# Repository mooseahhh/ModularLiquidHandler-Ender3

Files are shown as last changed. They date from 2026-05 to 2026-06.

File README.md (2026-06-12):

# Modular, Remotely Accessible, Open Source Liquid Handler — Ender 3 Pro
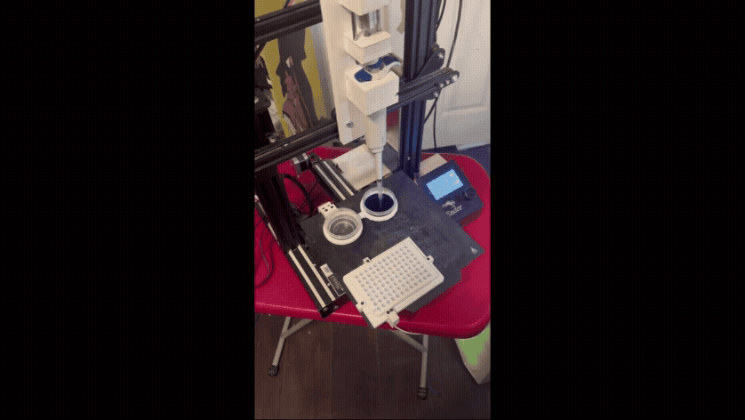
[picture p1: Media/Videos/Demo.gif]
Liquid handler demo


### Commercial liquid handlers can cost thousands of dollars and often offer little modularity. This project showcases a fully functional, remote-access capable liquid handler built by modifying a used Ender 3 Pro 3D printer for **under $150**.

## Features
- **Low Cost** —
  - Base build under $150 using a used/refurbished Ender 3 Pro; accessible without institutional funding
- **Modular Hardware** —
  - Built on a widely-supported 3D printer platform running open-source Marlin firmware; components are replaceable and the design is forkable
- **Precise, Calibrated Dispensing** —
  - semi-automated gravimetric calibration workflow CV% tracked as a primary acceptance metric  following ISO 8655 gravimetric principles
  - Well alignment, pipette well and reservoir immersion tests
- **Network Connectivity** —
  - Full remote operation via network access through OctoPrint + OctoEverywhere plugin: file uploads, G-code terminal, protocol monitoring, and calibration runs without physical access
- **Flexible Scripting** —
  - Gcode generating scripts can be utilized to make simple, customizable, lab protocols in workflows
- **Demonstrated Application** —
  - 24-column, 4-step 1:2 serial dilution protocol across a full 96-well plate in a 2-hour automated run
---
## Current Validation Results
| Metric | Value |
|---|---|
| Target Volume | 125.0 µL |
| Mean Volume | 126.85 µL |
| Mean Error | +1.85 µL (+1.48%) |
| Standard Deviation | 4.10 µL |
| CV | 3.23% |
| Trial Count | 10 |
---
## Table of Contents

- [Current Validation Results](#current-validation-results)
- [Build Resources](#build-resources)
  - [BOM(Bill of Materials)](#bom-bill-of-materials)
  - [CAD](#cad)
- [Software & Plugins](#software--plugins)
- [Repository Structure](#repository-structure)
- [Calibration](#calibration)
- [Serial Dilution Protocol](#serial-dilution-protocol)
- [Checklist / Roadmap](#checklist--roadmap)
- [License](#license)

---

## Build Resources

### Bill of Materials (BOM)

**Base build cost: ~$130**

|Main Base Items| Category  | Notes |
|---|---|---|
|**Creality Ender 3 Pro (used/refurbished)** | Motion platform | XYZ gantry + E-axis repurposed for plunger actuation |
| **Four E's Scientific P1000 single-channel manual pipette** | Pipette | Set to 125µL; drives through plunger stops via actuator |
|**Custom 3D-printed clamps, well plate holder, reservoir holders** |Deck hardware| STL files included in [`/CAD/STL_files`](/CAD/STL_files/) |

Full BOM with sourcing notes: [`/References/materials/BOM.csv`](/References/materials/BOM.csv)

---

### CAD

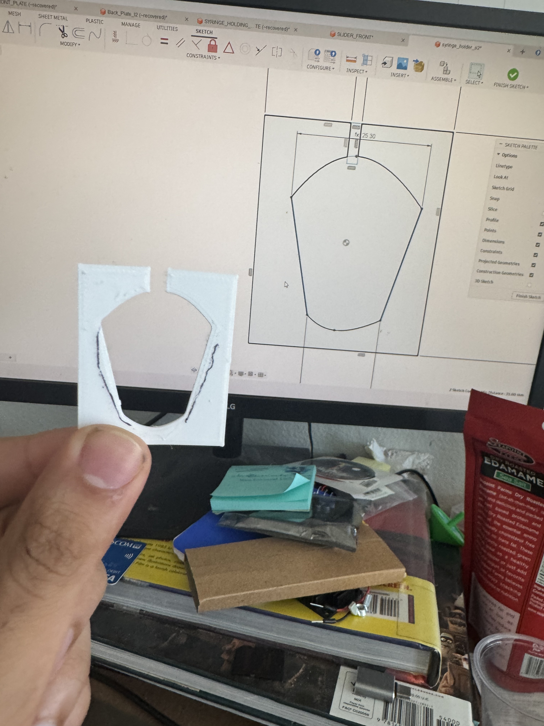
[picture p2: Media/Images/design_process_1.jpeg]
designing pipette holder


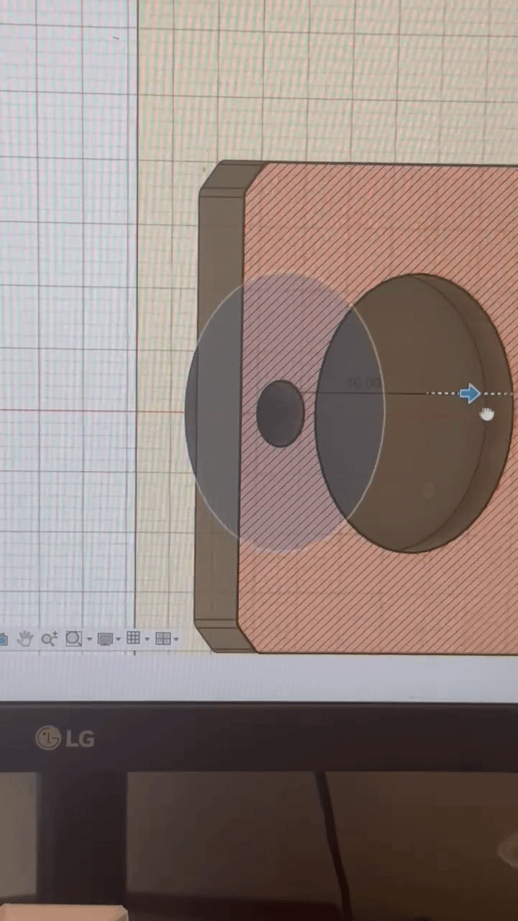
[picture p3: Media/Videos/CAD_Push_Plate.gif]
Push Plate CAD Cross section demo


All custom parts are designed in Autodesk Fusion. Source files are in `/CAD`; 
- print-ready STLs are in `/STL_files`
- modifiable F3D files are in `F3D_files`

| Component  | STL file | F3D file |
|---|---|---|
| Liquid handler arm mount | [`lh_arm_mount_i1.stl`]( CAD/STL_files/lh_arm_mount_i1.stl)|[`lh_arm_mount_i1.f3d`](CAD/F3D_files/lh_arm_mount_i1.f3d) |
| actuator plunger push plate | [`plunger_push_plate_i4.stl`]( CAD/STL_files/plunger_push_plate_i4.stl)|[`plunger_push_plate_i4.f3d`](CAD/F3D_files/plunger_push_plate_i4.f3d) |
| Pipette mount | [`pipette_mount_i2.stl`]( CAD/STL_files/pipette_mount_i2.stl)|[`pipette_mount_i2.f3d`](CAD/F3D_files/pipette_mount_i2.f3d) |
| 96-well plate deck|[`96_wp_deck_i2.stl`](/CAD/STL_files/96_wp_deck_i2.stl)| [`96_wp_deck_i2.f3d`](/CAD/F3D_files/96_wp_deck_i2.f3d)|
| vwr cell culture 96-well plate deck|[`vwr_96_wp_deck_i2.stl`](/CAD/STL_files/vwr_96_wp_deck_i2.stl)| [`vwr_96_wp_deck_i2.f3d`](/CAD/F3D_files/vwr_96_wp_deck_i2.f3d)|
| Reservoir holder |[`dual_holder_minicups_i1.stl`](/CAD/STL_files/dual_holder_minicups_i1.stl) | [`dual_holder_minicups_i1.f3d`](/CAD/F3D_files/dual_holder_minicups_i1.f3d) |
| Deck2Plate clamps |[`deck2plateClamp_I1.stl`](CAD/STL_files/deck2plateClamp_I1.stl)|[`deck2plateClamp_I1.f3d`](/CAD/F3D_files/deck2plateclamp_i1.f3d)|
| Deck2Bed clamps |[`deck2bedClamp_i1.stl`](CAD/STL_files/deck2bedClamp_i1.stl)|[`deck2bedClamp_i1.f3d`](/CAD/F3D_files/deck2bedClamp_i1.f3d)|
| Reservoir2Deck adapter clamp |[`res2deckClamp_i3.stl`](CAD/STL_files/res2deckClamp_i3.stl)|[`res2deckClamp_i3.f3d`](/CAD/F3D_files/res2deckClamp_i3.f3d)|

---

## Software & Plugins

### OctoPrint

OctoPrint runs on OctoPi OS on Raspberry Pi connected to the printer's control board, enabling full remote operation — file management, G-code terminal, print monitoring, and protocol execution without physical access to the machine.

Setup guide: [OctoPrint on Raspberry Pi (YouTube)](https://www.youtube.com/watch?v=9FYqQdan-lA)

### Plugins

| Plugin | Purpose | Link |
|---|---|---|
| Creality 2x Temperature Reporting Fix | Corrects erroneous temperature doubling on Ender 3 boards | [Plugin page](https://plugins.octoprint.org/plugins/ender3v2tempfix/) |
| OctoEverywhere | Secure remote access — no port forwarding required; connection is handled through the OctoEverywhere service | [Plugin page](https://plugins.octoprint.org/plugins/octoeverywhere/) |

---
## Repository Structure
```
ModularLiquidHandler-Ender3/
├── CAD/
├── STL/
├── Code/
│   ├── Tests/
│   │   ├── gc_test.py
│   │   └── gc_calibration.py
│   ├── solvent_fill.py
│   └── serial_dilution.py
├── References/
│   └── BOM.csv
└── README.md
```
## Calibration

- Z-height was calibrated using Pronterface and G92 Z0.
- E-axis positions corresponding to the pipette's upper, first, and second stops were determined empirically using gravimetric validation.

### Gravimetric Calibration
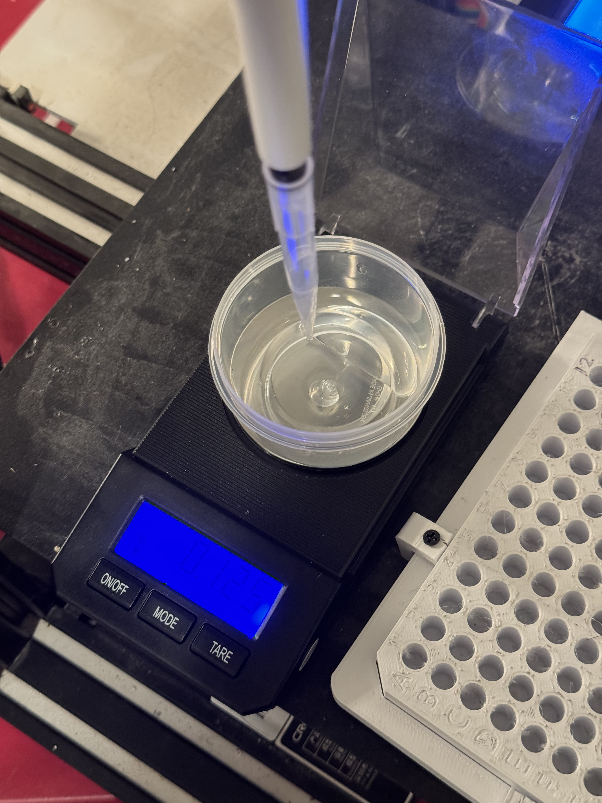
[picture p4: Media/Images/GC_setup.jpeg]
GC_setup_pic


Pipette accuracy is validated by measuring dispensed water mass and converting to volume. Water density at NTP (0.998 g/mL) is used for the conversion. CV% is the primary acceptance metric per ISO 8655.

**Step 1 — Generate test G-code**

```bash
python gc_test.py
```

- Outputs `test_gc_calibration.gcode`. Runs `TRIAL_NUM` aspirate/dispense cycles (default: 5), pausing after each dispense for scale reading via M0 host pause.

**Step 2 — Run the protocol**

- Load G-code via Octoprint or Pronterface. During each trial, tare the scale during the first pause and record mass of the dispensed liquid to `raw_data.txt` (one reading per line) during the second.

**Step 3 — Analyze results**

```bash
python gc_calibration.py raw_data.txt
```

Options:
- `--target-ul` — target transfer volume in µL (default: 125.0)
- `--output-dir` — output directory (default: `results/`)
- `--keep-raw` — do not clear raw data file after analysis

- Outputs a CSV with per-trial transfer mass, volume, and error, plus a summary `.txt` with average volume, standard deviation, CV%, and mean error against target.

**Step 4 — Iterate**

Adjust `E_FIRST_STOP` / `E_SECOND_STOP` based on mean error and re-run until CV and accuracy are within acceptable range.

---

## Serial Dilution Protocol

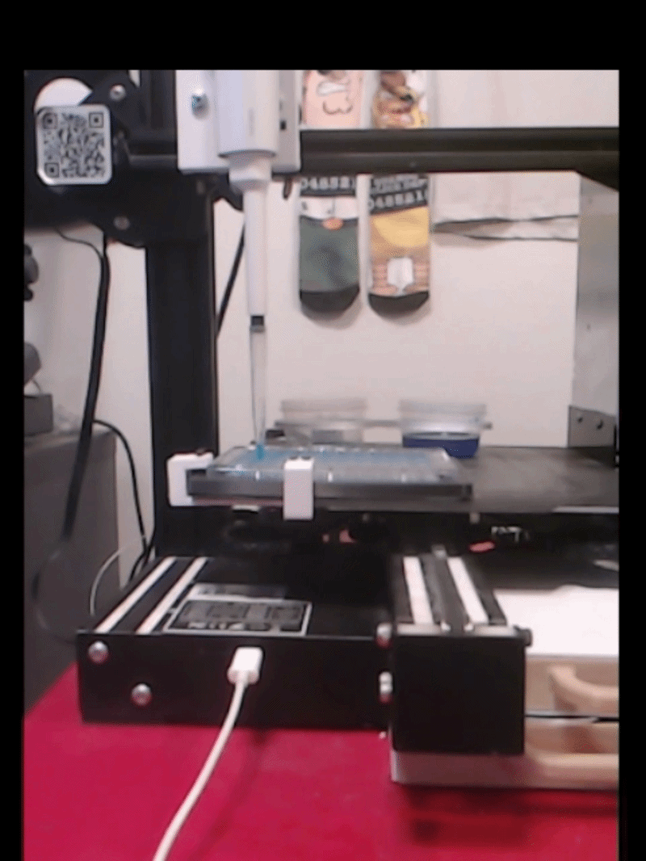
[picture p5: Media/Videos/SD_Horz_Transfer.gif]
Mixing and transfer of horizontal serial dilution


- Serial dilution is a foundational technique across molecular assays — including titer concentration curves in ELISA, library preparation for NGS, and reagent standardization. 
- This protocol demonstrates the liquid handler running 12 rows A-D vertical and 12 rows E-H Horizontal, 4-step 1:2 serial dilution across a full 96-well plate in a 2.5-hour automated run.

**Step 1 — Verify Calibration Constants**

Confirm `E_FIRST_STOP`, `E_SECOND_STOP`, and Z-height values are current before running any protocol.

**Step 2 — Fill Wells with Solvent**

- Add solvent reservoir with 50 mL H₂O
- Run: `python solvent_fill.py`
- Load and run: `solvent_fill_prot.gcode`

**Step 3 — Run Serial Dilution**

- Replace solvent reservoir with empty waste reservoir
- Add stock reservoir in second slot (40 mL + 2 drops of blue dye)
- Run: `python serial_dilution.py`
- Load and run: `half_vertical_half_horizontal_24_4_1n2_sd_prot.gcode`

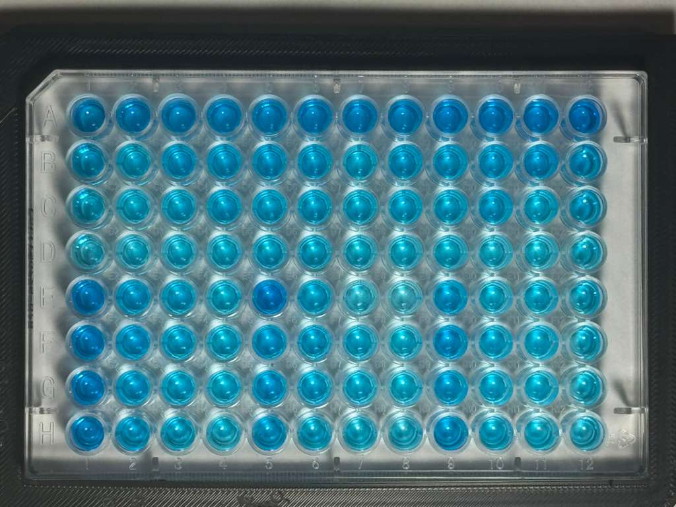
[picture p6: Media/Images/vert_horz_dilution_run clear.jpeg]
Completed Serial Dilution 96-well plate

- **Completed run of a 12 rows A-D vertical series, 12 rows E-H horizontal series 4, 1:2 Serial Dilution**

## Checklist / Roadmap

- [x] Single-channel syringe pump build
- [x] 96-well plate deck with custom clamp system
- [x] Semi-automated gravimetric calibration workflow
- [x] 24-column 4-step 1:2 serial dilution demonstration
- [x] OctoPrint + OctoEverywhere network integration
- [ ] RPi camera-based tip detection and alignment
- [ ] Parametric reservoir holder generating script for simplified custom STL holder generation
- [ ] Multi-channel head expansion
- [ ] Full protocol scripting interface
---
## License

Software: [Apache 2.0](https://www.apache.org/licenses/LICENSE-2.0)

Mechanical design: [Creative Commons Attribution 4.0 International](http://creativecommons.org/licenses/by/4.0/)



---

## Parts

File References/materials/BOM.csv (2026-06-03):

Last Updated: | 05/21/26
TOTALS | GROUP-INFO | Item | Purpose | Qty | Qty Used | Cost of items used | Approx Cost | Link | Notes
 | Base | Ender3-Pro | modifiable 3+1 axis machine base | 1 | 1 | 60.00 | 60 | https://www.ebay.com/sch/i.html?_nkw=ender+3+pro&_sacat=183062&_from=R40&_trksid=p2332490.m570.l2632
 |  | Four E’s P1000 manual pipette | Pipetting mechanism | 1 | 1 | 26.99 | 26.99 | https://www.amazon.com/dp/B01IP5Q8HU | a p200 is more suitable for this, but I already had this P1000
 |  | Saiper Flexible Couplings 5mm to 5mm (5pcs) Aluminum Alloy Joint Connector Compatible with NEMA 17 Stepper Motors, RepRap 3D Printer or CNC Machine, 3D Printer Accessories | couple screw rod to stepper motor rotor | 5 | 1 | 2.00 | 9.99 | https://www.amazon.com/dp/B07M5Q7HTV
 |  | 5 mm guide rods | guide plunger push plate linearly | 2 | 2 | 7.59 | 7.59 | https://www.amazon.com/dp/B082ZNSRBN
 |  | pla+ filament (1kg) | 3d printing material | 1 | 1 | 13.99 | 13.99 | https://www.amazon.com/ELEGOO-Filament-Toughness-Dimensional-Accuracy/dp/B0D41ZDC47 | can change for different filament just make appropriate slicer configurations.
 |  | m5 thread rod(.8 pitch, 200mm) | thread rod moves effeciently | 5 | 1 | 2.12 | 10.6 | https://www.amazon.com/Uxney-Stainless-Corrosion-Resistant-Projects%EF%BC%885/dp/B0FMNTPCC6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 | found single piece for 2.39 at my local ace hardware
 |  | 1110 Pcs M3 Screws and Nuts Set, Countersunk Bolts and Nuts Assortment, Black Phillips Flat Head Machine Screws with Washers Set(M3 Screw Kit, Black) | necessary hardware for printed parts | 1 | 1 | 6.99 | 6.99 | https://www.amazon.com/dp/B0CMCDWWRZ?ref=ppx_yo2ov_dt_b_fed_asin_title&th=1
 |  | Super Glue | adhesion of guide rods and reinforcing hex nut to push plate. | 12 | 2 | 1.00 | 5.99 | https://www.amazon.com/Adhesive-Cyanoacrylate-Plastic-Ceramic-Leather/dp/B0F6XZFXDB
 |  | Small Round Container | reservoir containers used | 1 | 2 | 7.00 | 3.5 | https://www.ebay.com/itm/376219876119 | dollar tree - 10 for $2 dollars (2, 2 oz polypropelene sauce containers would also suffice) - it actually cost 40 cents
 |  | Distilled Water | solvent | 1 | 1 | 1.39 | 1.39 | https://www.target.com/p/baby-water-distilled-formula-128-fl-oz-good-38-gather-8482/-/A-92243568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
 |  | Coloring Dye | for making visual solute | 1 | 1 | 3.99 | 3.99 | https://www.target.com/p/food-coloring-38-egg-dye-4pk-1-2-fl-oz-market-pantry-8482/-/A-82325334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
TOTAL |  |  |  |  |  | 133.06 | 151.02
 | Optional | 1.5M Motor-Connector Cables | extend z axis cable range | 3 | 1 | 2.33 | 6.99 | https://www.amazon.com/dp/B0GWMTCMVF | ender3 z axis cable felt too short so 1.5mm cable installed middle wires swapped for stepper motor compability
 |  | silicone bumpers(3/8 inch) | helps prevent sliding of well plate deck on printer bed | 16 | 4 | 0.75 | 2.98 | https://www.homedepot.com/pep/Everbilt-3-8-in-Clear-Self-Adhesive-Round-Bumper-16-Pack-41-H1006/328914125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
 |  | sandisk ultra 64gb microsd | for transfering prints and os memory for rpi | 2 | 2 | 40.11 | 40.11 | https://www.amazon.com/dp/B07XDCZ9J3
 |  | VWR 10062-900 Tissue Culture Plate 96-Wells-F Sterile | sterilized 96 well plate | 1 | 1 | 3.00 | 3 | https://www.ebay.com/itm/226150753653
 |  | rpi 4b 8gb | to add network capabilites via octo print aswell as camera based calibration and monitoring | 1 | 1 | 187.41 | 187.41 | https://www.amazon.com/Raspberry-Pi-Computer-Suitable-Workstation/dp/B0899VXM8F
 |  | power supply for rpi 4b | power for raspberry pi | 1 | 1 | 9.85 | 9.85 | https://www.amazon.com/dp/B0FPF3PBGV
 |  | Arducam Motorized Focus Pi Camera, Autofocus for Raspberry Pi Camera Module, Motorized Lens, Software Precise Manual Focus, OV5647 5MP 1080P | adjustable focus camera for calibration and monitoring | 1 | 1 | 14.99 | 14.99 | https://www.amazon.com/dp/B07SN8GYGD
OPT TOTAL |  |  |  |  |  | 258.44 | 265.33
BASE+OPT TOTAL |  |  |  |  |  | 391.49 | 416.35

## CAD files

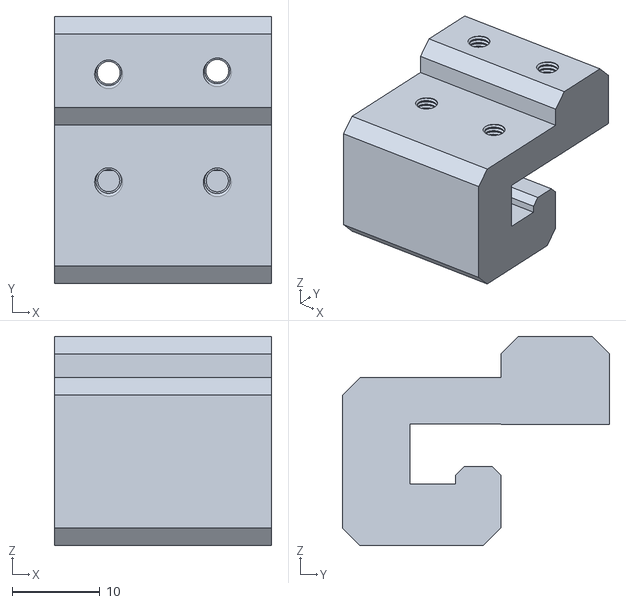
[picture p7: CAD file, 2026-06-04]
CAD/STL_files/res2deckClamp_i3.stl
24.7 x 30.3 x 23.8

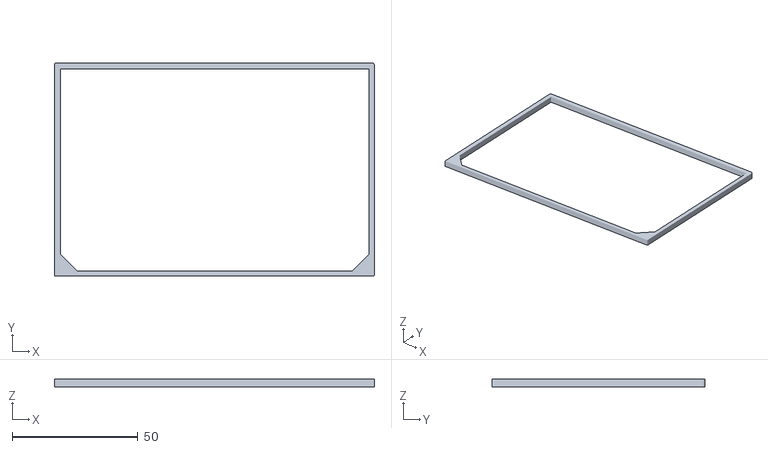
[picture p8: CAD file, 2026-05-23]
CAD/STL_files/tests/cover_pltfrm_96_test_wp_deck_dimensions.stl
127.4 x 84.9 x 3.00

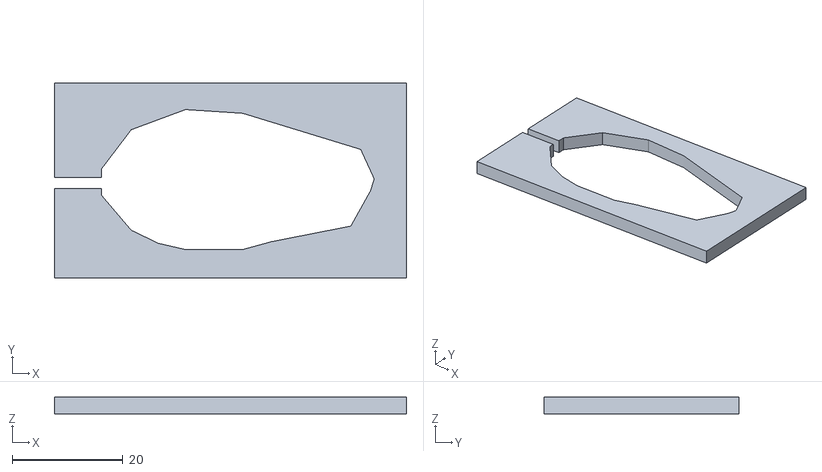
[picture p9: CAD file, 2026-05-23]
CAD/STL_files/tests/pipette_holder_s2_i1_test_plate_to_measure_if_holder_fits_pipette.stl
63.6 x 35.3 x 3.00

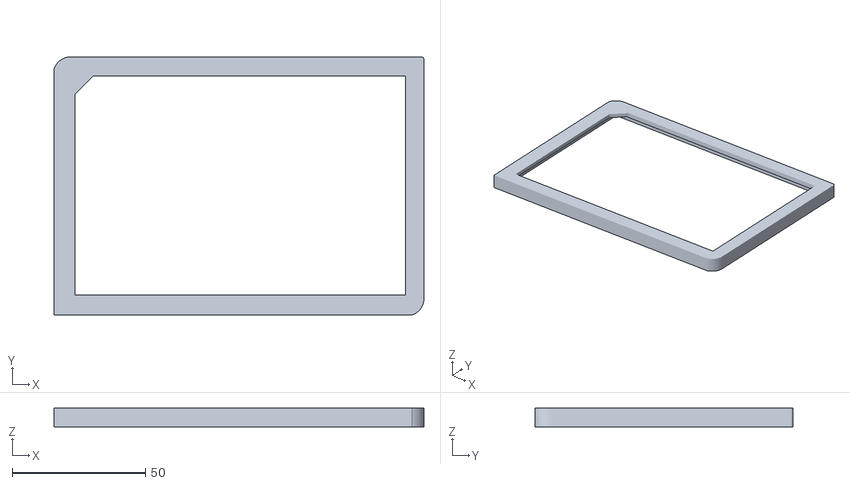
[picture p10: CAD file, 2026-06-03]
CAD/STL_files/vwr_96_wp_deck_i2.stl
138.7 x 96.8 x 7.00

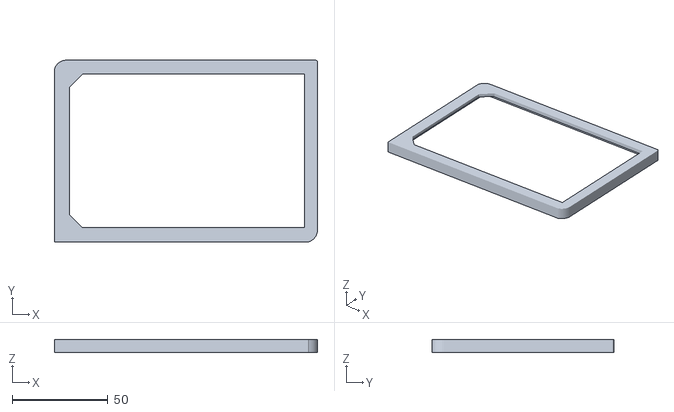
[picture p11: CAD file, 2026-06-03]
CAD/STL_files/96_wp_deck_i2.stl
137.2 x 94.8 x 7.00

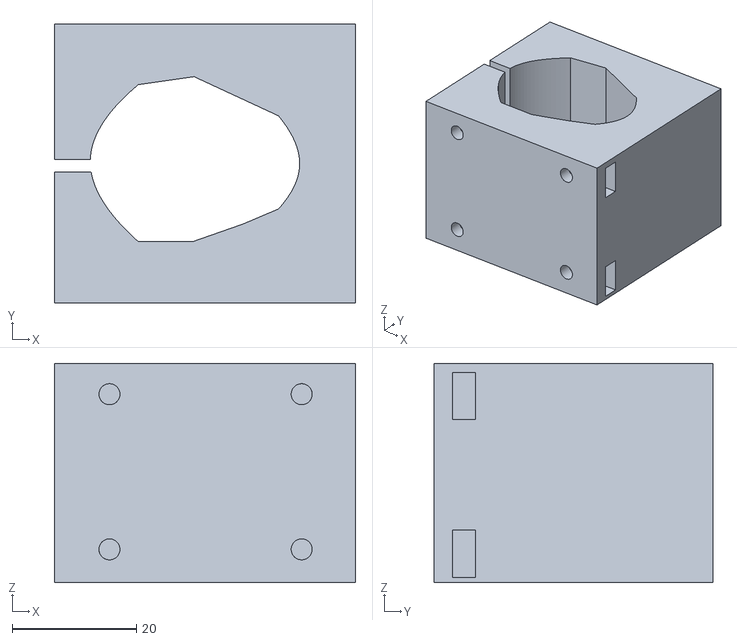
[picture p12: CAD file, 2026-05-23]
CAD/STL_files/pipette_mount_i2.stl
48.5 x 45.0 x 35.3

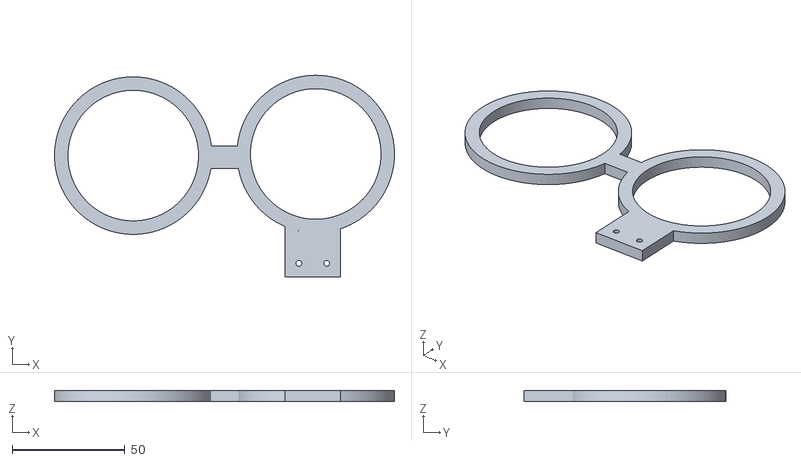
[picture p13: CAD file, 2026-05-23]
CAD/STL_files/dual_holder_minicups_i1.stl
151.1 x 89.6 x 5.00

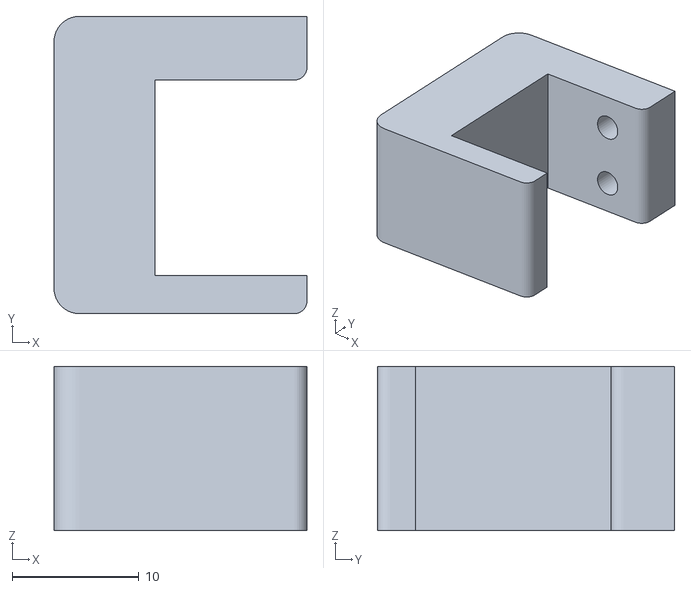
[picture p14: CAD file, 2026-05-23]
CAD/STL_files/deck2bedClamp_i1.stl
20.0 x 23.5 x 13.0

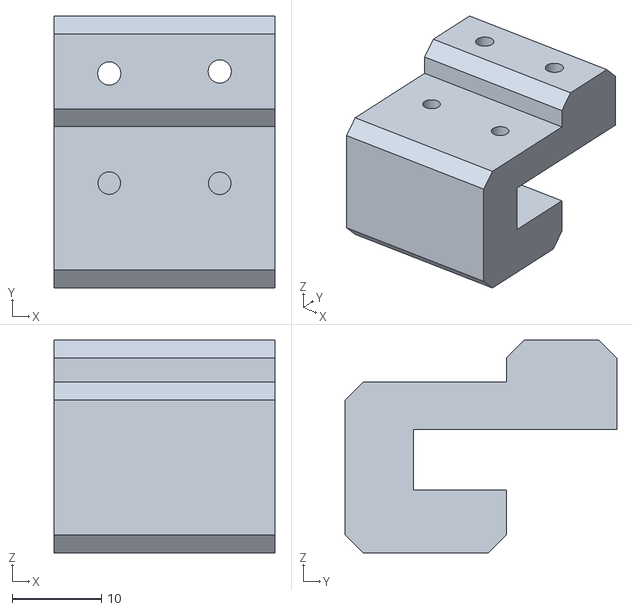
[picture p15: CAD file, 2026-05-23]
CAD/STL_files/res_bot_bed_clamp_i1.stl
24.7 x 30.3 x 23.8

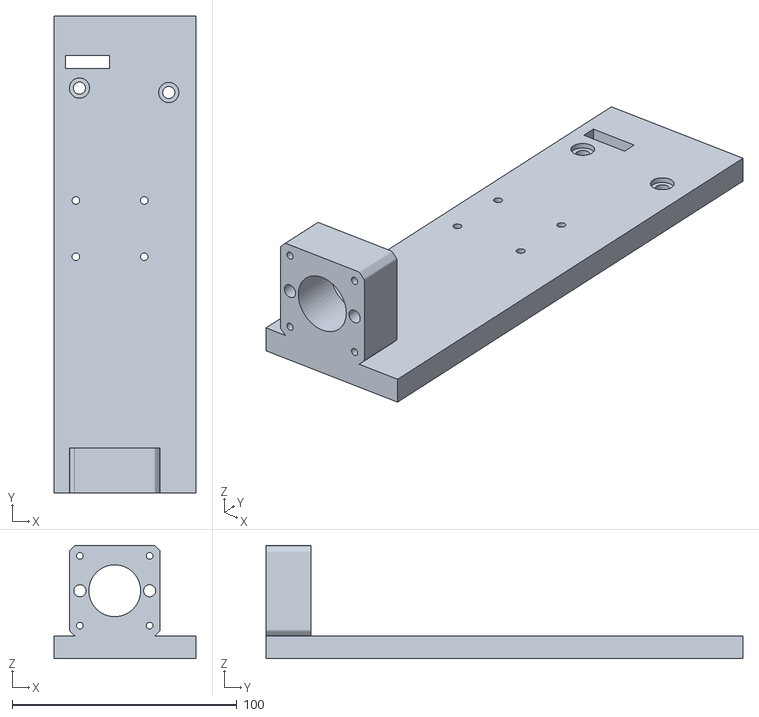
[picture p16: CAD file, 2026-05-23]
CAD/STL_files/lh_arm_mount_i1.stl
63.1 x 212.0 x 50.2

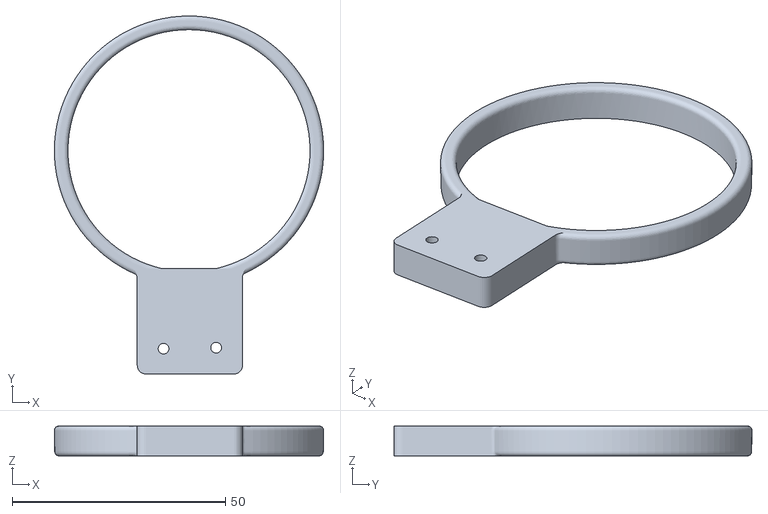
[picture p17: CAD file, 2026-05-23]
CAD/STL_files/res_cup_i1_for_6oz_karat_cup.stl
63.2 x 84.0 x 7.01

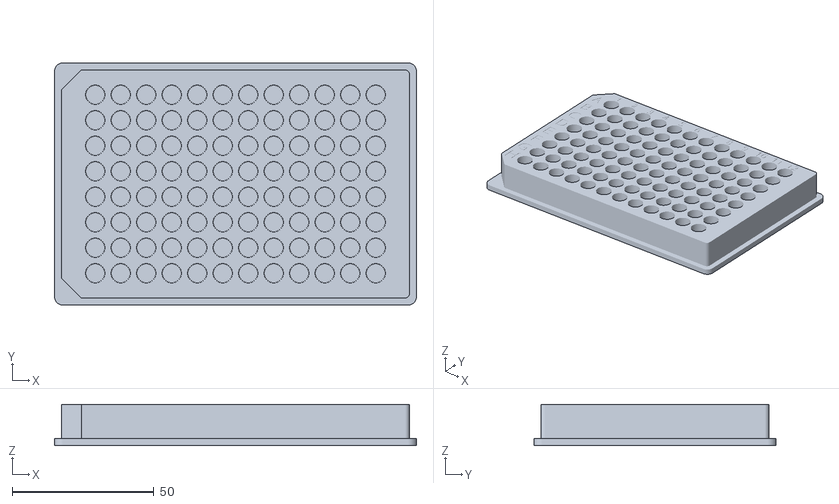
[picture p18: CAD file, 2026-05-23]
CAD/STL_files/96 Well Plate, F-bottom, Standard - 96 Well Plate, F-bottom, Standard.stl
127.8 x 85.5 x 14.6

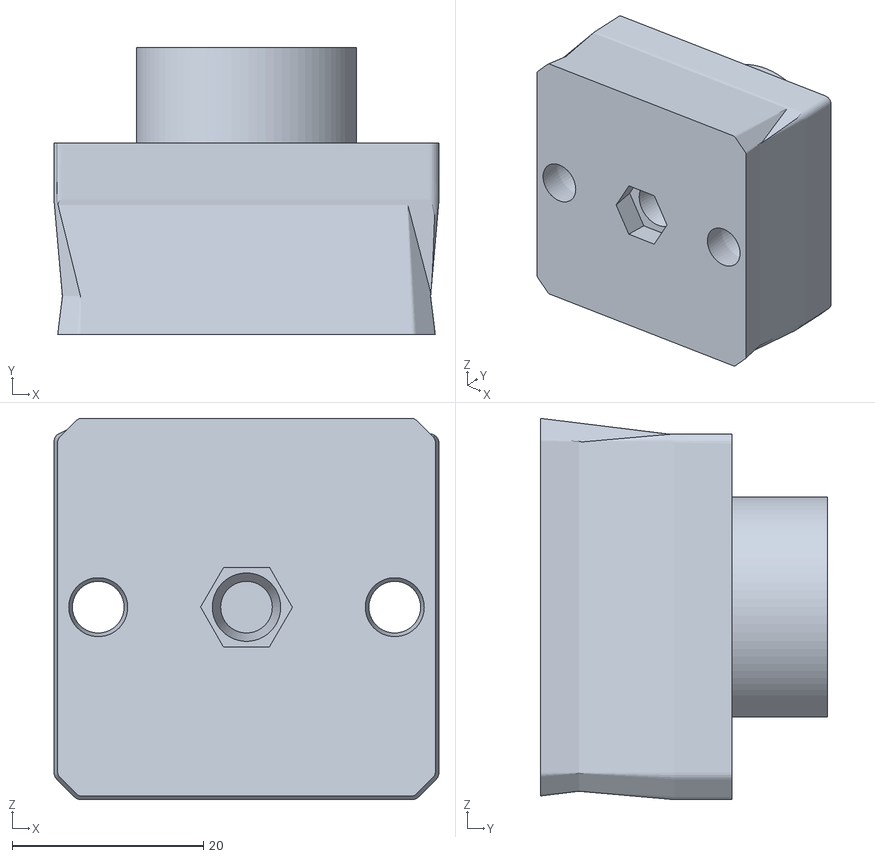
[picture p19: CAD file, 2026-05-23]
CAD/STL_files/plunger_push_plate_i4.stl
40.2 x 30.0 x 39.9

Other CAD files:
CAD/F3D_files/96_wp_deck_i2.f3d
CAD/F3D_files/deck2bedClamp_I1.f3d
CAD/F3D_files/deck2plateClamp_I1.f3d
CAD/F3D_files/dual_holder_minicups_i1.f3d
CAD/F3D_files/lh_arm_mount_i1.f3d
CAD/F3D_files/pipette_mount_i2.f3d
CAD/F3D_files/res2BedClamp_i1.f3d
CAD/F3D_files/res2deckClamp_i3.f3d
CAD/F3D_files/vwr_96_wp_deck_i2.f3d

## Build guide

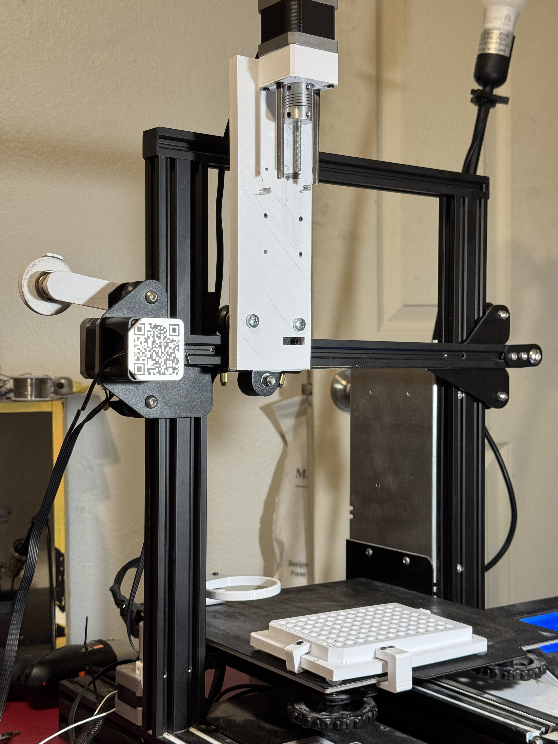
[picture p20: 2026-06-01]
Media/Images/assembly_process.jpeg

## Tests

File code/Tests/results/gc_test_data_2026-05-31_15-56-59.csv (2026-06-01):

trial | transfer_g | transfer_ul | error_ul | error_percent
1 | 0.121 | 121 | -3.76 | -3.01
2 | 0.128 | 128 | 3.26 | 2.61
3 | 0.124 | 124 | -0.75 | -0.60
4 | 0.125 | 125 | 0.25 | 0.20
5 | 0.127 | 127 | 2.25 | 1.80
6 | 0.133 | 133 | 8.27 | 6.61
7 | 0.125 | 125 | 0.25 | 0.20
8 | 0.125 | 125 | 0.25 | 0.20
9 | 0.134 | 134 | 9.27 | 7.41
10 | 0.124 | 124 | -0.75 | -0.60

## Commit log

2026-05-08 sd path no reserv or push plate
2026-05-23 CAD and Reference files added
    [96 Well Plate, F-bottom, Standard - 96 Well Plate, F-bottom, Standard.stl, 96_wp_deck_I1.stl, 96_wp_deck_i1.f3d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]
2026-06-01 solvent_fill.py created,parameter redundancies removed
    [gc_test_data_2026-05-31_15-56-59.csv]
2026-06-01 deck_config.py added to cleanup constant usage
    [96_wp_deck_i4.stl]
2026-06-03 reorganize files, reorganize Readme
    [96 Well Plate, F-bottom, Standard - 96 Well Plate, F-bottom, Standard.stl, 96_wp_deck_i1.f3d, 96_wp_deck_i2.f3d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]
2026-06-03 Refine README content and formatting
    Updated README to improve clarity and consistency in descriptions, features, and BOM details.
2026-06-03 Revise README for clarity and accuracy
    Updated project title and improved readability in the README. Added calibration details and corrected spelling errors.
2026-06-04 CAD and README revisions
    [pipette_mount_i2.f3d, pipette_mount_i2.stl, res2BedClamp_i1.f3d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]
2026-06-11 Fix case sensitivity in BOM file reference
    Corrected the case of the materials directory in the BOM reference.
